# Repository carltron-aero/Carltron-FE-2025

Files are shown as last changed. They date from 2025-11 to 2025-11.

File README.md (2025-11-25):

# Team Carltron - Future Engineers 2025

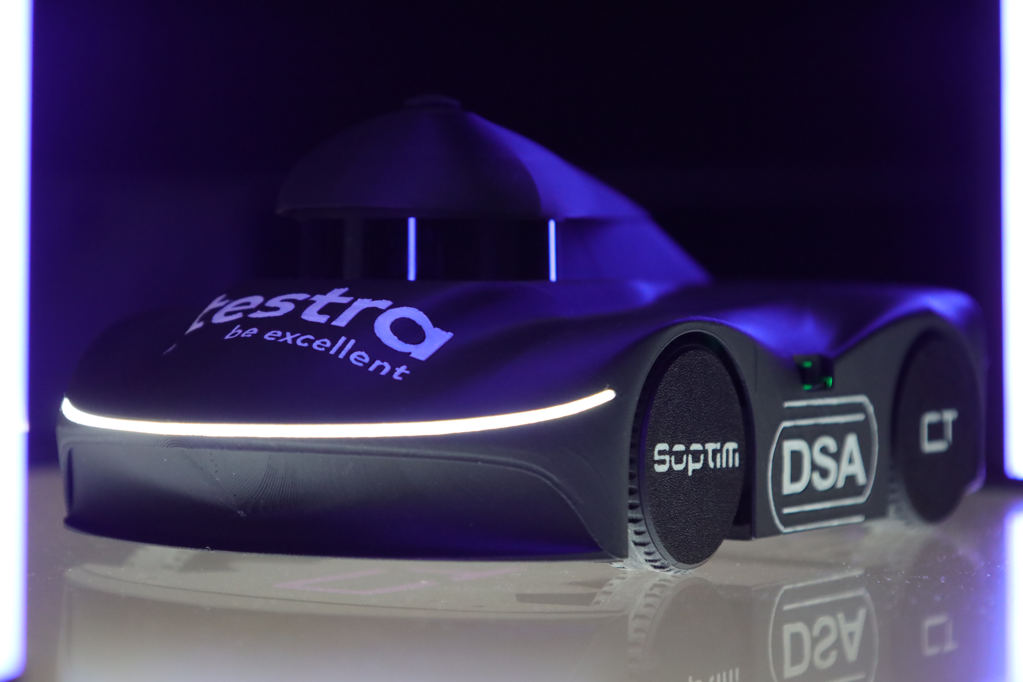
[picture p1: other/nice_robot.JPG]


<center>This is the Future Engineers project repository by team Carltron for the 2025 World Robot Olympiad International Final.
</center>

### Our Journey so far...
The 2025 season is actually our first season both in Future Engineers and WRO in general. After participating in multiple robotics competitions over the past few years, we were looking for a new challenge, when we found out about the Future Engineers Category in december 2024. Due to exams and other obligations though, we were only able to start working on our robot in April 2025, one month before our regional competition in Aachen, Germany. This challenged us to make our design strategies more efficient and also streamline our project management. After getting a working robot ready just in time, our first big moment came on the 17th of May at our regionals, where we managed to secure the qualification for the german finals by taking 1st place.
Our robot had jumped over the first hurdle, which was a big relieve and motivated us to go all in on the national 
competition. But not everything was well and good. Our first robot (V1) had also shown some flaws during its live 
competition runs, so we already had a long list of ideas on how to improve it and diminish or remove these issues. 
Development went on to the German finals, where we were able to secure 2nd place, qualifying us for the 
international final. Now, since than a lot has happened. A completely from the ground up new robot happened among 
others. But let's not spoil too much, cause that's what the rest of this documentation is all about, right?

## Design Strategy
As a basis for all decisions we would make in our entire process, both hardware, software and everything in between 
we first decided to lay down some fundamental design principles to help us make good decisions in the developement 
of our robot from the get go.

- For the general design of both our hardware and software systems, we always try to simplify all solutions to their 
base requirements. For example this means solving issues on the lowest level possible; hardware > software. 
- Question all common solutions: Why is something "always" done this way? Is it really the right approach for our 
  specific case?
- Minimize complexity! A highly complex system is hard to work with and will probably bring serious reliability issues.

# Mobility Management
## Motorization and Chassis

In the beginning of our preparations we looked at different kinds of robot kits and systems that we might build upon.
However, none of them seemed really perfect for what we had in mind. Either the form-factor wasn't quite right, the 
chassis would have needed significant changes anyway, or it just took away too many development opportunities.

So we decided to completely design our own vehicle from scratch using CAD software. That way we would also have 100 
% control over every ever so slight detail that would need to be tweaked.

We had already developed our core concentric sensor system previously, which already gave us a couple of constraints 
concerning the layout and size of the robot. And developing a concept for the layout of the robot with all of its 
biggest components was also the first main step we took towards developing the chassis of our robot.

Our 3D printer probably was the most important tool throughout our entire hardware-development phase. We printed all 
parts of our chassis in PLA Filament with fine-tuned printing parameters, which can be found in the printing files 
inside the */models* directory. By using 3D CAD designed Parts that we printed ourselves, we also managed to iterate 
through different design approaches quickly, in most cases with under one hour per hardware iteration.
 
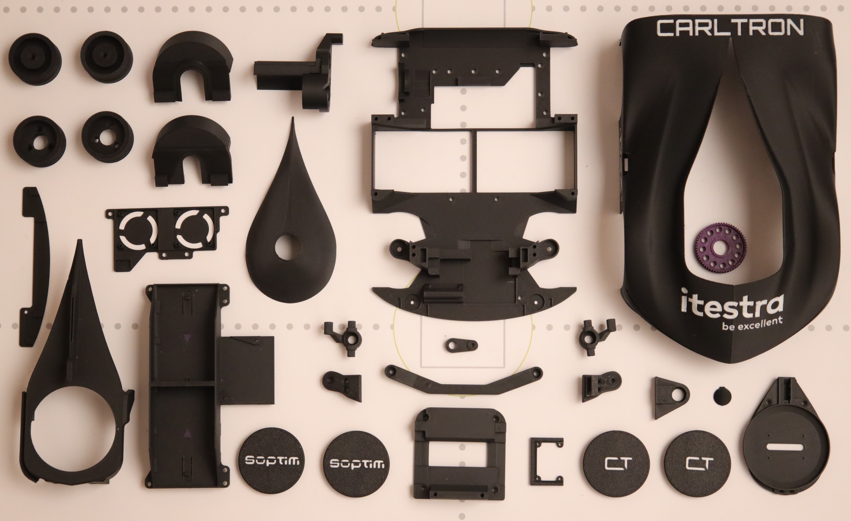
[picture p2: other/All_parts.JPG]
> 
> All 3d-printed Parts for the robot

### Drivetrain
For the choice of our drive system, the central factors were power and compactness. At first we considered
implementing an all-wheel drive with two steering axles for maximum maneuverability. But our research showed that
our robot would have to be significantly larger than planned for that solution to work.

From the outset we set a guiding principle for the robot’s development: every aspect of the design must aim for the simplest solution with the lowest susceptibility to failure. Accordingly, we performed calculations and experiments on turning circles and performance for different drive options to determine what the simplest overall system would look like that still fully meets our requirements:

1. It must reliably achieve a usable speed range of 0.12 to 1.4 m/s.

2. It must have sufficient traction to transfer motor power to the ground.

3. It must have a maximum turning radius of 0.55 m.

4. The steering must be able to transition fully from one extreme deflection to the other within 0.3 s.

In the comparison we found that a conventional approach—with the rear axle as the drive axle and the front axle used purely for steering—offered the best compromise between compactness and performance.
This configuration also gave us the opportunity to develop a fully custom steering system.

As in most cases, a lot of our chassis- and robot-development is rooted in well based design decisions.

#### Motor selection
For our main drive motor, we were primarily constrained by space it could get in the robot. When developing a 
conceptual layout, we found that we would need a 25 mm diameter motor would be just the right fit for our chassi.

As another strict requirement for the drive motor, we needed it to have an encoder, since we intended accurately 
control the physical wheel speed using the data from this sensor as well as distance data

So then we started looking for such a Motor, and actually fairly quickly found the Motor+Encoder combination we use 
till this day. It is a DC electric motor, that runs at 1000 rpm nominally.

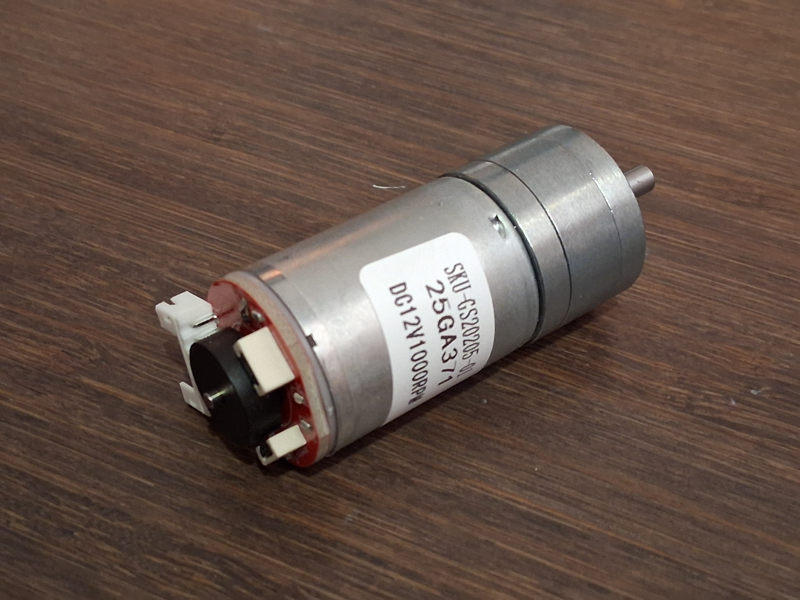
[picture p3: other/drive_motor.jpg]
>
> The drive motor theat was selected 

This motor theoretically also lets us fully use the required speed range from our development phase up to 1.5 m/s, 
however we found in testing the software that a limit to 0.75 m/s made a lot more sense in order for reaction times 
to still be adequate for avoiding crashes.
To ensure high agility despite using front-wheel steering only, a differential on the rear axle is very helpful
because it allows the driving wheels to move independently. This lets the inner wheel follow a smaller turning radius without unnecessary slip and without the wheels losing traction. At the regional competition we used an off-the-shelf rear axle with a differential. However, its precision and reliability did not meet our requirements. In addition, using this and other standard components in the drivetrain forced us to design the rest of the robot around those parts rather than integrating them well, since they were not developed specifically for our use case.

To keep the robot’s form factor small and maintain full flexibility in the overall design, we decided to develop
our own differential gearbox that would fit perfectly into the rest of the robot’s layout. We tested various 
bearings, gears, and motor couplings for this. Ultimately we developed the differential gearbox shown below, which—like 
most of the robot’s other components—was designed from the ground up by us in the 3D CAD software Onshape. We 
3D-printed the Differential in PETG-CF for its improved toughness and abrasion resistance. So far we have done about 
50h of testing without the 3D-printed differential showing any wear whatsoever. 
However, we bought the axle off the shelf for durability reasons.

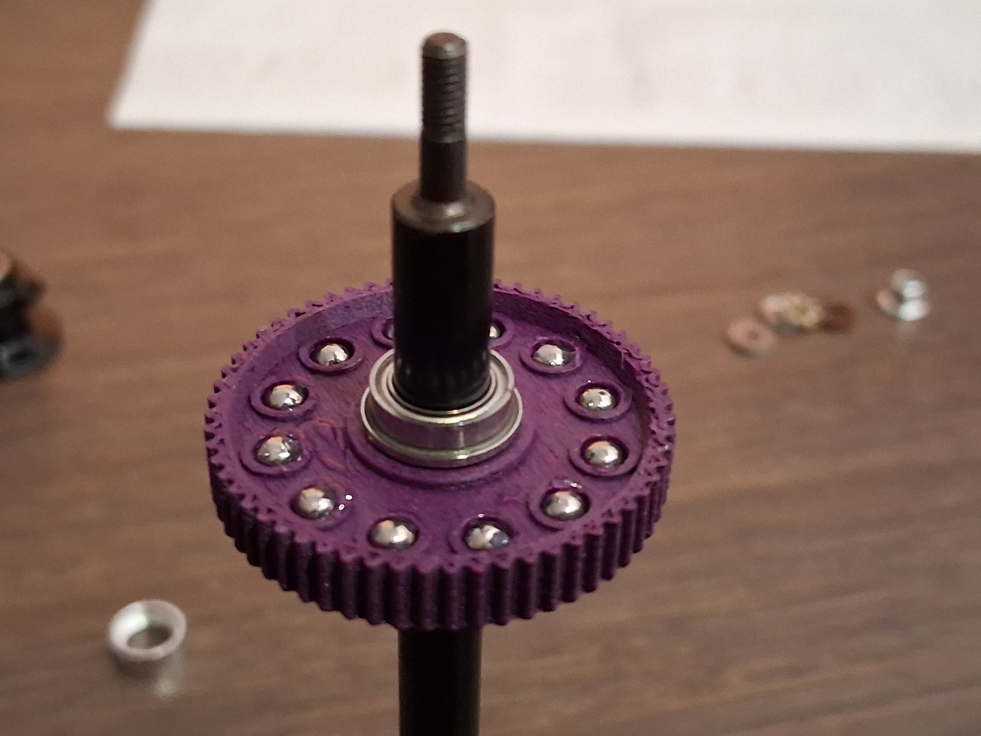
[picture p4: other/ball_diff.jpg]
> 
> Ball differential (half), purple part was developed and manufactured by us

The type of differential we ended up implementing is a so called ball-differential. While it achieves the exact same 
effect as normal geared differentials for the drivetrain, it takes a very different approach by using a double 
clutch design, that uses the spherical character of the balls to reverse the counter-rotation. 
A more detailed explanation of the ball diff can be found here: https://en.wikipedia.org/wiki/Ball_differential

Besides compactness, improved precision and efficiency, ball differentials also have a very distinct feature by 
default: They are so called "limited slip differential", meaning that we can fine tune just how much slippage we 
want to allow between the wheels to optimize for the best power transfer on the game field.

By developing this ball diff ourselves we also were able to perfectly tune the gear ratio to the drive motor, which 
is now 16:60. However, we could simply change this parameter if we wanted to adjust the velocity range of the robot.
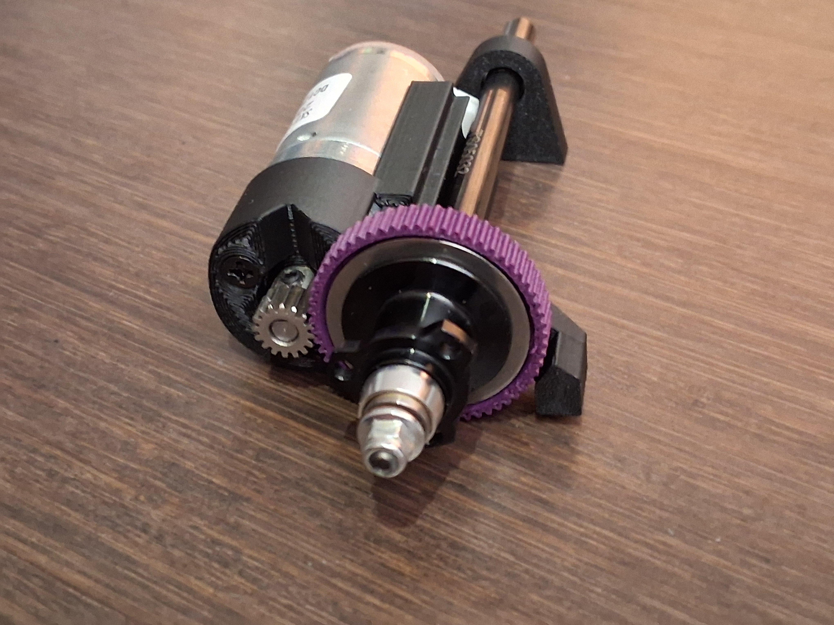
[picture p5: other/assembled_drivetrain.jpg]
> 
> Fully assembled drivetrain system

### Steering System

As part of our Drivetrain/Chassis Development process we had found that especially if we were to attempt the parking 
challenge, we would need to significantly improve the steering agility of the robot, to an extent that could not be 
achieved by tuning or using off the shelf components.

So we did a full redesign of the entire steering system, making it more compact and drastically increasing the 
steering angles. We finally managed to minimize the turning diameter of the robot to just 42 cm, falling well below 
the required maximum of 55 cm set in the development phase. This would come in clutch for leaving and entering the 
parking lot reliably, since now we could actually do it in one single motion, where previously multiple direction 
changes were required.

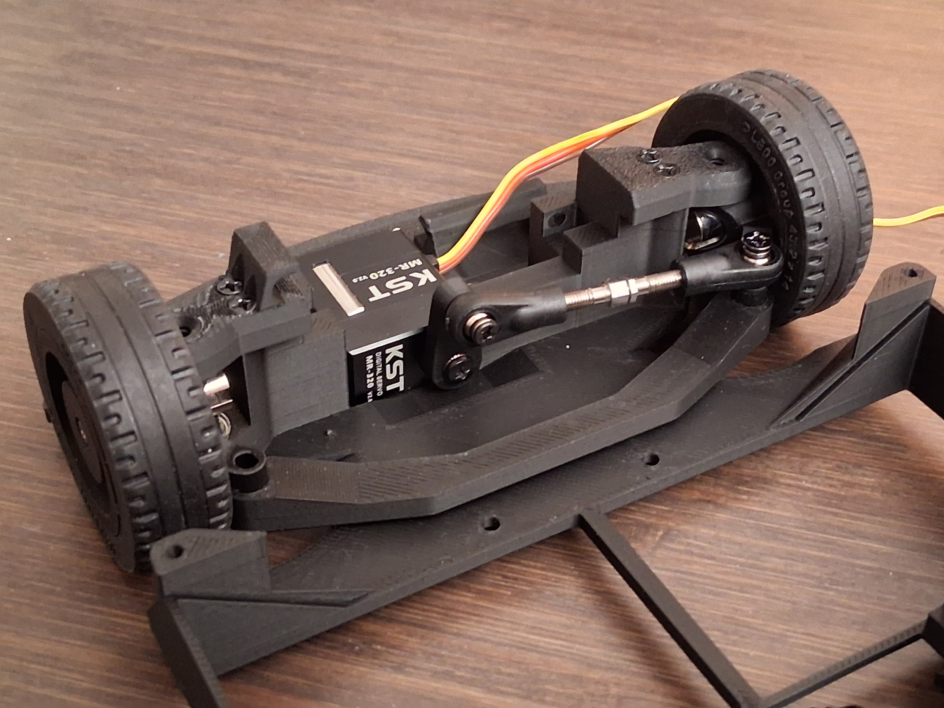
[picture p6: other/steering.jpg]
> 
> Newly developed Steering system for improved agility

We had previously used quite a large steering servo, that didn't work as reliably and didn't provide the speed and 
precision we set out to achieve with our new target values for the steering system.

So we went looking for a new Servo, fitting the requirement, comparing different models till we decided to use the 
KST MR320 180°. This smaller servo that actually provides better performance than our previous one also helped us 
significantly in optimizing the robot layout, since the our concentric core sensor assembly could now be lowered, 
giving it more margin for measuring imprecision.

In order to test our new steering kinematics we now also started using CAD based simulations, that allow us to go 
through all the required operational modes and movements, without requiring a lot of 3D-printing and subsequent 
plastic pollution.

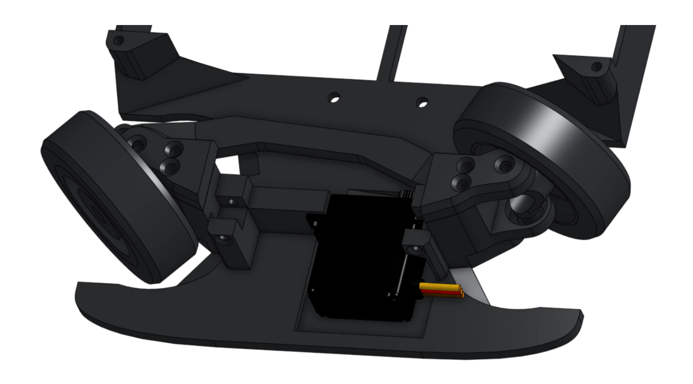
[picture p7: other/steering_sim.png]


### Bodywork

We developed a replaceable bodywork for our robot, that protects the components from environmental influences, 
directs the cooling airflow through the robot and provides it with front and rear lighting for status indications 
and more luminance for the obstacle scanning.

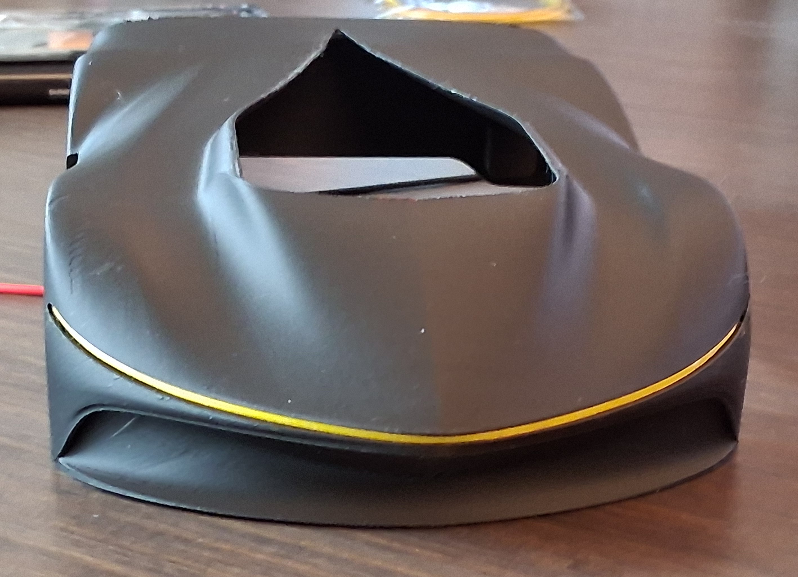
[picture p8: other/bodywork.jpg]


The bodywork gets held on the chassis magnetically, making it very easy to hot-swap whenever something needs done 
"under the hood".

### Aerodynamics

Another advantage of the bodywork we designed is the improved aerodynamic efficiency the bodywork provides to our robot.
We ran CFD (computational fluid dynamics) simulations as a virtual wind tunnel, to compare different versions in 
their aerodynamic characteristics.

This is a visualization of the latest simulation results:
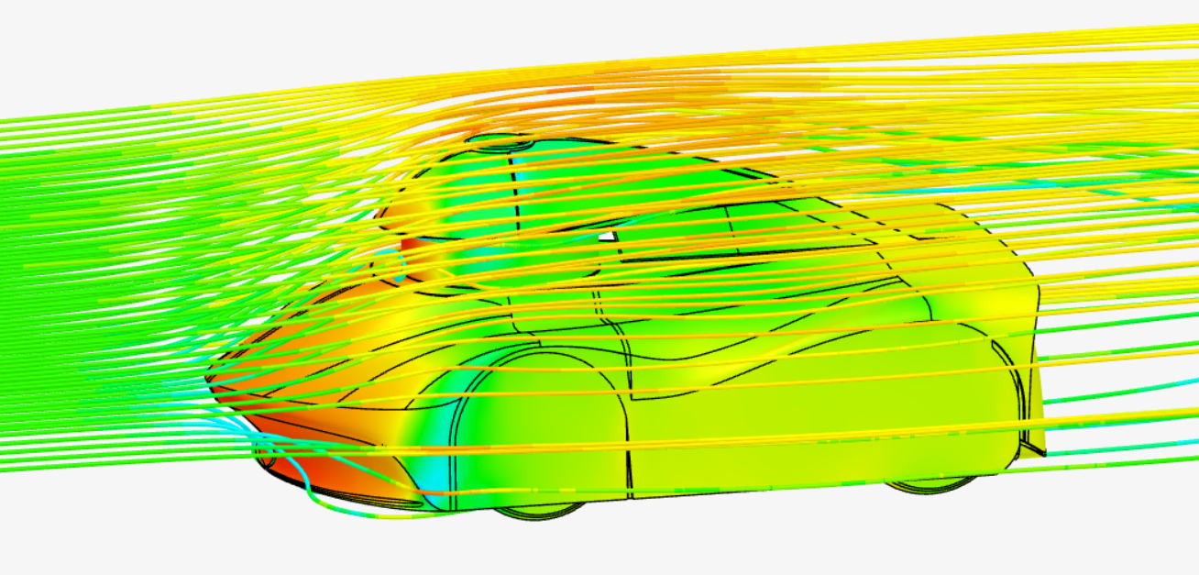
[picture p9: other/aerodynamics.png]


As you can see, we managed to create a clean air split along the front bonnet of the robot, guiding the air over two 
moulds in the bodywork towards the rear of the car without flow separation. By extending the rear spoiler overhang 
we managed to almost completely remove any vortices caused by rearward flow leaving the vehicle, which is especially 
important to reduce the overall drag of the vehicle.

The simulation however for example also shows that the round surface of the lidar scanner causes some vortices to 
form in th low pressure zone right behind the sensor, which would be one of the next step to be mitigated in terms 
of aerodynamic optimization.

And just as a disclaimer: You are right to assume that these kinds of aerodynamic optimizations do not really have 
any measurable effect on the scale and speeds that Future Engineers is running on. But for us this is all about 
trying new and interesting things. We were able to learn very much about aerodynamics by doing these simulations and it 
even was a lot of fun trying it out. Can recommend.

# Power and Sense Management

## Compute

Before any data from any kind of sensor becomes really useful, there has to be an algorithm that uses it to create 
some kind of outcome. And for that algorithm to become useful it needs to run on something - so it seems like we 
need a computer.

We have previously already worked with Raspberry Pis and in this case the versatile GPIO capabilities of the 
Raspberry Pi 5 combined with its small footprint and its well maintained codebase as well as a great community made the 
choice easy. We chose to use the Raspberry Pi 5 8gb, to be sure that enough memory would be available for our high 
speed camera frame buffer.

## Sensors

The selection of sensors is obviously one of the most defining characteristics in the concept of any Future 
Engineers robot. So let's start with a first principles approach to figure out, what kind of sensors are required to 
achieve the strategy we intended to implement.

Since our goal was to design a robot that could reliably localise itself on the playing field in 
any place or situation, we found that we would need sensors that could give us a reading of the robots 
physical surroundings in real time, which could be used for multiple purposes such as obstacle detection, 
localisation and collision avoidance. By taking a closer look at the actual playing field were working with in the 
Future Engineers category, we can see that all walls, barriers and obstacles are on a single flat level, or in other 
words a single plane. This is because all of these relevant objects on the playing field have the same height of 100 mm.

If we can get a planar 360° reading of our physical surroundings we can from any point of the playing field see so- 
called "characteristic spots". Examples of such spots would be the corners of the outer and inner walls, the 
barriers of the parking lot or the placement of specific obstacles. As long as our planar reading is precise enough 
and has an adequate resolution, we, theoretically, can do all localisation, navigation and path planning based on 
this single 360° sensor reading.

Well, the great thing is, because we are not the first humans tackling challenges of autonomous navigation, there 
already are quite mature sensor technologies that can give us the exact 360° physical reading that we need: They're 
called 360° Lidar sensors. 

Lidar (Light Detection and Ranging) is a Laser-based distance measuring technology that works by sending out light 
beams and measuring the time their reflections from any objects take to return. Since lightspeed is constant, this 
technology can give pretty accurate distance readings, whilst having a much more targeted measuring window (e.g. 
compared to ultrasound distance sensors). 

But what makes these sensors give 360° readings of their surroundings if they have such a targeted range? It's 
kind of simple but also genius: You simply spin the sensor really fast (multiple times per second). By doing that 
whilst taking multiple thousand readings every revolution of the sensor, you get a full 360° view with distance 
measurements in all directions.

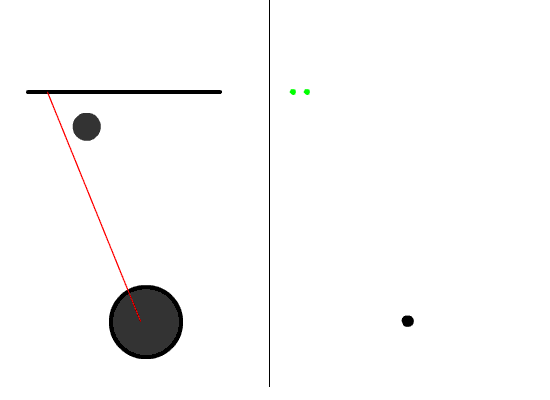
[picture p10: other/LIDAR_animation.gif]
>
> 
> Animation of the concept of a 360° Lidar Sensor

After finding the right type of sensor for our application, the next step is selecting a specific model that 
perfectly suits the requirements set by our specific challenge.

Since our robot will have to use the sensor readings while driving, we need the sensor to provide us with readings 
regularly. Our testing showed that a rate of 10 hz worked to an acceptable extent while best results could be 
achieved using sensors running at 15 hz or more. 

Concerning the resolution of the sensor, we need it to detect the obstacles that only have a 5 cm width from the 
robots' perspective, at a range of up to 2 m.

We also need a sensor performance, that can reliably detect the black walls of the game field both at ranges of up 
to 4 m and shallow angles, which could arise when driving close to a wall.

Also, importantly, we need it to have a form-factor, that lets us easily integrate it into our robot and that fits 
under the 10 cm height, so we can actually get the sensor reading in the plane of the game field.

We created this decision matrix to help us find the ideal 360° Lidar sensor:

| Criterion | **RPLIDAR S3** | **RPLIDAR S2** | **D900 / LD19 Plus** | **RPLIDAR A2** |
|---|---|---|---|---|
| **Update rate ≥10 Hz** | 🟢 10–20 Hz adjustable | 🟢 10 Hz fixed | 🟡 6–13 Hz range | 🟢 Up to 10 Hz |
| **Best at ≥15 Hz** | 🟢 Supports ≥15 Hz | 🟡 Limited to ~10 Hz | 🟡 Upper end ~13 Hz | 🟡 10 Hz max typical |
| **5 cm @ 2 m resol.** | 🟢 0.1125° ultra fine | 🟢 0.1125° ultra fine | 🟢 ~0.7–0.8° sufficient | 🟢 Fine enough for 5 cm |
| **Range margin beyond 4 m** | 🟢 40 m max range | 🟢 30–50 m variants | 🟢 12 m radius | 🟢 12–16 m range |
| **Black wall @ 4 m** | 🟢 10% refl. to 15 m | 🟢 10% refl. to 10–15 m | 🟡 Spec at 70% refl. | 🟡 Dark targets less specified |
| **Shallow-angle dark surfaces** | 🟢 Optimized low-reflectivity dtof | 🟢 Good low-reflectivity handling | 🟡 DTOF, less data published | 🟡 Triangulation, more sensitive |
| **Height < 10 cm** | 🟢 ~41 mm total height | 🟢 ~38.9 mm height | 🟢 ~33.5 mm height | 🟢 ~41 mm height |
| **Compact footprint for small robot** | 🟢 55×56 mm compact body | 🟡 77×77 mm footprint | 🟢 ~38×38 mm footprint | 🟡 Larger A-series footprint |
| **Eye safety, outdoor light** | 🟢 Class 1, 80 kLux resistant | 🟢 Class 1, IP65 rated | 🟢 Class 1, 30–60 kLux resistant  | 🟡 Indoor-oriented, less robust  |
| **Integration ecosystem, ROS support** | 🟢 Strong ecosystem, drivers | 🟢 Same Slamtec ecosystem | 🟡 Good, but more fragmented | 🟢 Widely used, many examples |
| **Cost level** | 🟡 Higher, premium Slamtec | 🟡 Mid-high price tier | 🟢 Low-mid price range | 🟢 Affordable A-series choice |
| **Form factor for 10 cm plane** | 🟢 Ideal low profile scanner | 🟢 Low optical window height | 🟢 Very low, cube-like | 🟢 Fits under 10 cm |
| **Overall match to requirements** | 🟢 Best fit for challenge | 🟡 Very strong alternative | 🟡 Good budget compromise | 🟡 Usable, but less optimized |

So the choice fell to the RPlidar S3 Sensor. Especially its ability to provide us with adequate resolution at a 15 
hz rotation rate due to its high sample rate, made the best choice clear to be this one. 

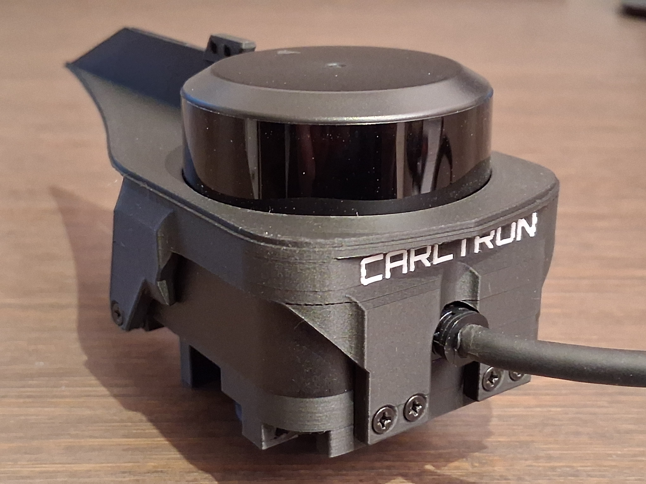
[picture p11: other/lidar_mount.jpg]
> 
> RPlidar S3 Sensor installed on its mounting hardware

Since we want to be able to use the 360° Lidar capabilities of this sensor to its fullest abilities, we decided to 
design our robot, so that the Lidar sensor would have an unobstructed surround view. This simply means that now 
components of the robot should reach into the field of view of the Lidar. But the sensor also should still sit well 
underneath the 10 cm top height mark of the walls and obstacles. Sitting to high might cause the sensor to simply 
look "over" obstacles and walls, as soon as the lidar sensors mounting is not perfectly plane. the closer we can 
bring the Lidar sensors measurement plane to the height middle of the 10 cm game field height, the better.

Getting physical 360° planar readings already gets us quite far in perceiving precisely what kind of obstacles are 
placed where and how to avoid them. But one crucial bit of information for the Future Engineers Challenge is still 
missing and can not be determined just by the readings from our Lidar sensor: The **color** of the obstacles. 

Since the detection of the color of the obstacles has to be performed on different angles from the point of view of 
the robot, a camera with a wide field of view is commonly used to tackle this and similar challenges. In most cases 
the camera simply looks forward in the driving direction and depending on the setup, the position of the obstacles 
is either determined by the camera image directly, only providing relative readings, or by use of primary physical 
sensors such as a 360° lidar sensor giving absolut position readings.

In both cases, with the camera simply mounted forward facing, either image analysis has to be 
performed on each whole frame to find the obstacles using visual cues, or a conversion from the physical planar 
readings of the lidar to the different perspective of the camera frames has to be done. Both of these common options 
can become quite compute intensive and cause lag as well as creating another possible source of unreliability.

So we tried to come up with a more efficient and reliable way to both detect the obstacles position and their color.
After trying out different set-ups and configurations, we found a novel technique that required some special 
modifications, but allowed us to skip the compute intensive full frame analysis on each camera frame entirely and 
without any conversions.

### Camera

Our approach: We can reliably detect the obstacles and their position using the Lidar sensor, just not their color. 
From the Lidar data we directly know the exact angle in the circular Lidar scan, the obstacle is located at from the 
Lidars' perspective.
Now, what if instead of the camera having a different perspective than the Lidar sensor, it simply had the exact 
same perspective? How can we get the camera to provide us with a 360° planar view just like the Lidar sensor?

We use a **custom 360° camera**.

We found a camera lens that provides a circular field of view of 222° and modified an existing camera sensor module 
based on the IMX219 Sensor
to capture the full image circle of this lens. And yes, that fov is more than 180°, meaning that the 
camera can basically look behind its own sensor plane. Since we capture the full image circle (meaning all light
the circular lens shines out its back), this actually goes for all directions from the center of the frame in the 
exact same way.

For visualisation, this is a sample frame taken from the custom 360 camera:

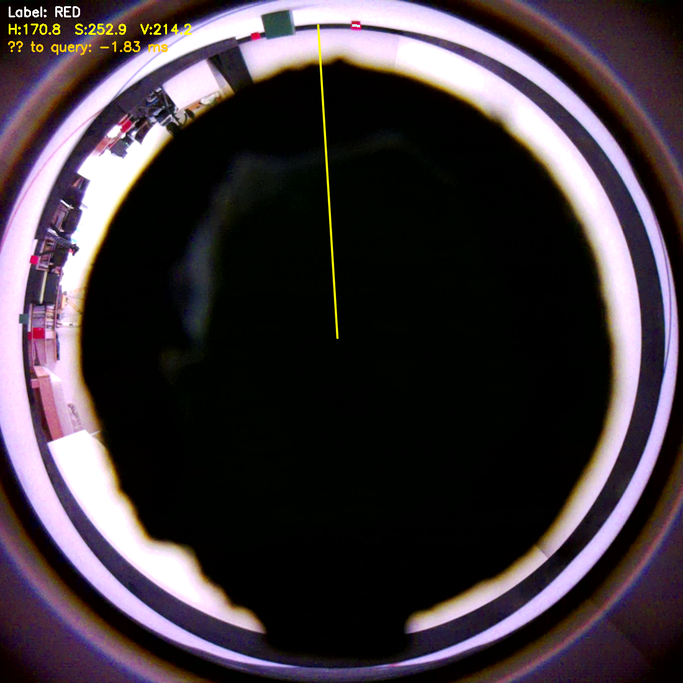
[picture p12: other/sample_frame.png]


As you can see, the camera is positioned on the game field looking straight upwards. You can also see, that the 
camera has a clear view of all walls of the game field all around itself. This means that, as is also visible by the 
various colored obstacles positioned on the field for the sample frame, the camera has a 360° view of all the 
obstacles. 

But there is still one difference to the lidar data: While the lidar directly gives us planar readings of the 
sensors surroundings, the camera captures part of an optical sphere that converges to a single point. In order to 
analyze a plane with the surroundings of the camera, we simply have to look at a ring-shaped region of interest in the 
frame 
that has a fixed radius. This radius has to be chosen precisely so that it is on the same exact plane as the camera 
sensor.

And with all that in place, we simply position the camera sensor directly over the center of rotation of our lidar 
sensor but still under the 10 cm max height of the obstacles, et voilà - we have a camera that gives us a planar 
360° reading that is concentric with the planar 360° reading of the Lidar.

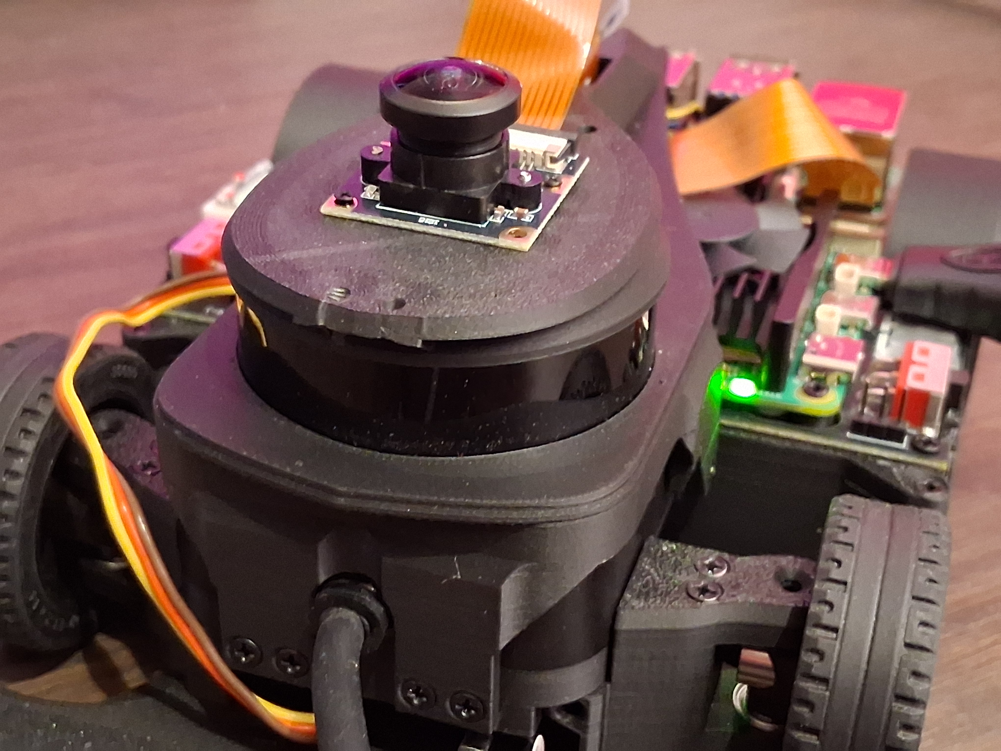
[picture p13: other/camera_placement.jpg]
> 
> 360° camera positioned concentric above the lidar sensor

This means that we can simply 1:1 map the angles from our Lidar scans, on which we detect obstacles, onto our camera 
frames. Instead of analysing the frame for obstacles, we just have to detect them physically using Lidar and then 
just get the color reading on a couple of pixels on the corresponding angle of our ring-shaped region of interest in 
order to tell the color of any detected obstacles. 

Since no actual image analysis has to take place, and we also don't need any conversions for the different sensor 
perspectives, our color detection actually only adds on the order of a few milliseconds to any obstacle analysis, 
making it much more efficient than any other approaches we tested.

This special approach to the lidar - camera  combination for obstacle and color detection is also a great example of 
our fundamental design strategies: Instead of simply using the standard approach of mounting the camera forward 
facing - following the motto "we'll fix that later in the code...", we reduced the issue to its core and came up 
with novel approaches until we found one that is both simpler more reliable and efficient for this specific challenge. 

Mounting the camera on top of the Lidar sensor however also comes with a noticeable downside: The data from the 
camera has to somehow come from above the lidar scanning plane below it - to where the rest of our electronics 
resides to analyse the data. So somehow, the camera cable has to cross through the field of view of the Lidar sensor.
To mitigate the effect of this, we decided to put our so called "shark fin" behind the lidar sensor, that allows a 
flatband cable for the camera to reach the Raspberry Pi whilst also holding the custom camera housing and mounting 
structure.

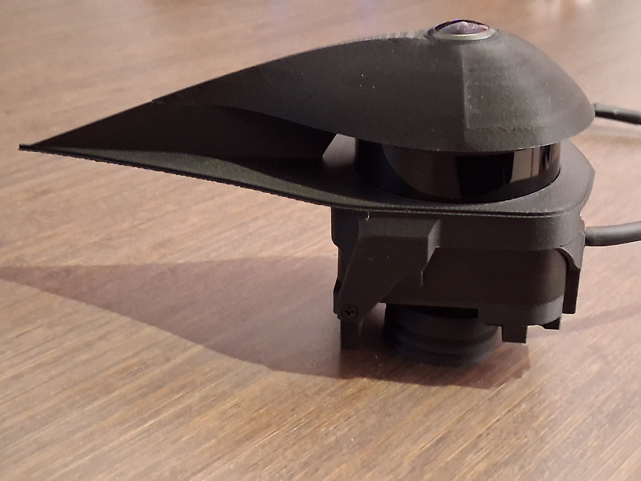
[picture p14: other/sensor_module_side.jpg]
> 
> Assembled sensor module with Lidar sensor, shark fin and camera on top with the camera housing

As might have already caught your attention looking at the sample frame provided earlier, the center of the frame 
inside of the ring-shaped region of interest is actually blacked out in the sample frame. This is due to us 
employing a small partial lens cap, that simply blocks any lights from shining on the camera sensor from directly 
above in order to improve  color precision during the challenge.

### Other Sensors

While Lidar and camera theoretically could provide enough information to fully solve the Future Engineers challenge, 
in practice some secondary sensors are also needed to improve performance and get precise readings for specific 
aspects on the robot.

The first additional sensor is our IMU (inertial measurements unit), which combines a gyroscope with a magnetrometer 
and additional acceleration readings. For its reliability and internal sensor fusion capabilities we chose the 
BNO085 IMU. We mainly 
use the 
gyroscope, both as part of our drive control 
algorithms to 
keep driving in a straight line as well as a secondary check for the localisation algorithm to make sure we're 
always using the correct regions of interest on a specific side. It also is used to count the solved sections in the 
open challenge

We also specifically chose a drive motor with an encoder. An encoder allows us to precisely measure how many 
revolutions our motor (and therefor the wheels) does in any given time frame, which lets us read both the physical 
distance our wheels have done as well as the actual physical speed were currently doing, decoupling driving a 
specific distance or at a specific speed from guessed timing values and changing battery state of charge (etc).

## Power Supply

### Selection of batteries

In order to determine the kind of batteries we would need to adequately power our robot, our first step was getting an overview of the power consimption of all the components we intended to use:

| Component | Power in W (peak, including voltage conversion losses) |
|---|---|
| Drive Motor | 14 |
| Steering Motor | 11 | 
| Raspery Pi | 15 |
| Lidar Sensor | 4 |
| Various Sensors / IO (IMU, LED, Camera, etc.) | 4 |
| **Sum** | **48** | 

>*These wattage values were obtained by combining values from the specific data sheets of the components as well as our own measurements.*

So, our batteries would need to provide ~50 Watts at peak. Our own measurements show, that over long term running, our specific system requires an average of 22 Watts constantly.

Additionally, we want to run our drive motor directly off the batteries without a voltage conversion. This is because any conversion losses would directly impede the performance of our drive train. Minimizing the required components (another converter in this case) also follows our general design strategy to keep all system aspects as simple as possible. To run our drive motor off the batteries directly, they need to provide provide a voltage between 14 - 18V.

As additional requirements, we want our batteries to be widely available in case we need to get spares, not too expensive, safe while in use and charging and we want to use a quick connect/disconnect system, that lets us swap out batteries with ease. They should also give us enough capacity to do at least an hour of testing on one battery to save time, so the batteries need to provide a capacity of at least ~30 Wh.

So we compared different kinds of commonly used batteries for our requirements:

| Criterion | 2× **LP-E6** series | 4S **LiPo RC** pack | 4S **18650 Li-ion** pack | 12-cell **NiMH** RC pack |
|---|---|---|---|---|
| **Voltage** | 🟢 16 V nominal | 🟢 14.8 V nominal | 🟢 14.8 V nominal | 🟢 14.4 V nominal |
| **Energy** | 🟢 ~39 Wh pack | 🟢 ~33 Wh pack | 🟢 ~38 Wh pack | 🟢 ~43 Wh pack |
| **Density** | 🟢 High Li-ion density | 🟢 High LiPo density | 🟢 Very high density | 🟡 Lower specific energy |
| **Peak power** | 🟢 3.5 A, ~56 W | 🟢 Very high current | 🟢 Several amps continuous | 🟢 High discharge capability |
| **Availability** | 🟢 Widely sold camera battery | 🟡 Hobby / RC channels only | 🟡 Cells common, packs niche | 🟡 Declining RC availability |
| **Safety** | 🟢 Protected, low risk | 🔴 Damage, fire risk higher | 🟡 Needs BMS protection | 🟢 Chemically very robust |
| **Charging** | 🟢 Simple LP-E6 chargers | 🟡 Requires balance charger | 🔴 BMS-aware charger needed | 🟡 Dedicated NiMH charger |
| **Swap mech.** | 🟢 Latching sled, foolproof | 🟢 XT plug quick swap | 🟡 Less standardized packs | 🟡 Bulky stick swapping |
| **Durability** | 🟢 Hard plastic shell | 🟡 Soft pouch, fragile | 🟡 Depends on pack case | 🟢 Rugged cylindrical cells |
| **Cost** | 🟡 Higher cost per Wh | 🟢 Lowest cost per Wh | 🟡 Moderate cost per Wh | 🟡 Moderate, heavier packs |
| **Form factor**  | 🟢 Compact brick | 🟡 Flat pouch, padding | 🟡 Cylinder cluster, bulky | 🟡 Long stick, heavy |
| **Overall match**| 🟢 Best system-level fit | 🟡 Acceptable, worse usabiliy | 🟡 Acceptable, complex integration | 🟡 Not adequate, heavy and bad usablity |

Due to their safety track record, wide availability, flexibly integrable form factor and standardized mounting system, we decided to use two LP-E6 type batteries running in Series. These provide up to 6 A at approximately 8 V each. Therefore, when connected in series, these two batteries giving us a total power capacity of around 56 W at 16V, nicely fitting our power requirements with some margin. 

### Voltage Management

Our different components each require specifc voltages which we need to supply to them reliably:

| Voltage | Components |
|---|---|
| 3.3 V | IMU, Camera, Motor Encoder, IO-LEDs, Lighting Bridge |
| 5.1 V | Raspberry Pi, Lidar Sensor |
| 8.4 V | Steering Servo, Cooling Fans |
| 16.0 V  | Drive Motor |

So there are four discreet voltage rails that need to be supplied reliably:

Our Raspberry Pi already provides an internal 3.3 V rail, that is used both for logic IO and power supply up to 500 mA for external components via the GPIO, which is more than enough for the Sensors and IO we want to run at 3.3 V, since they require a combined maximum of ~380 mA.

Both the Lidar Sensor and the Raspberry Pi need to be supplied with 5.1 V. While the Raspberry Pi can be supplied with up to 5 A, this is only necessary when running power hungry external components on its USB Ports. Since we do not use the USB ports during operation, we can still run the Pi 5 at full power when supplying int with 3 A. Our Lidar Sensor requires a maximum of 0.8 A on startup, bringing our total required power on the 5 V rail to 3.8 A. We decided to use a 5 A Step-Down Buck Converter for the 5 V Supply that is connected as seen in our Power Rails diagram.

At 8.4 V, the cooling fans of our robot use ~250 mA each and our Steering Servo needs ~1.4 A at peak. They are supplied by a smaller 3 A Step-Down Buck Converter.

The drive Motor is run directly off the Batteries, removing the need for any additional converters. Changes in the supply voltage based on the batteries state of charge are fully mitigated by our encoder-based drivetrain controller algorithms, as will be discussed later in the documentation.

This schematic provides an overview of how the different voltage rails are connected:
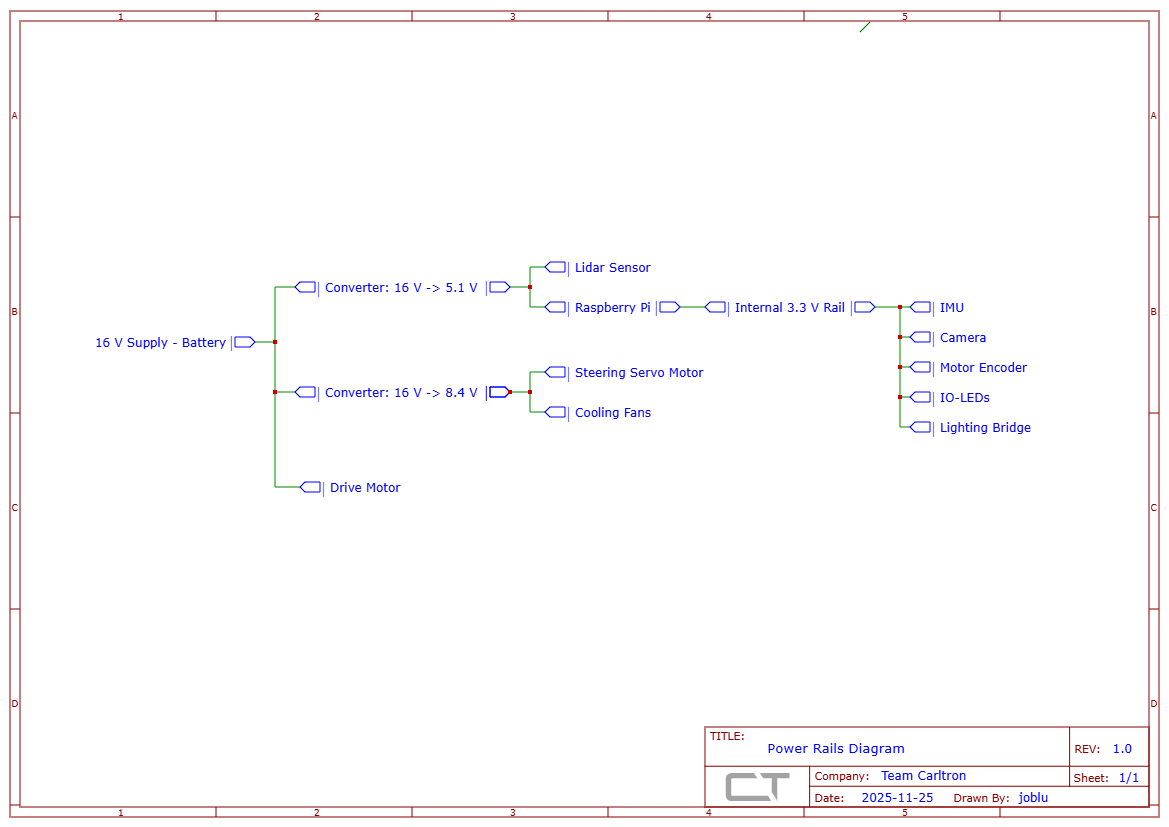
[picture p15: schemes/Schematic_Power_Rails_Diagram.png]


The separate Buck Converters used for the 8.4 V and 5.1 V rails also decouple all the sensitive electronics and sensors from our drive train power systems, preventing any voltage ripple and inconsistencies caused by sudden power changes in our drivetrain and steering systems.

To operate the Raspberry Pi and the batteries under optimal conditions, we also installed an actively air-cooled heatsink on the Raspberry Pi, as well as passive cooling elements on the voltage converters. In addition, we mounted the two main cooling fans under the rear of the robot to provide constant airflow from the front wheel housings, across all electronic components and converters, and out through the bottom of the chassis. These fans fully replace the air inside the robots bodywork every 4 seconds, making sure that all components can run at peak performance without getting hot.

### Custom Mainboard

For distributing power to the various components and ensuring communication between the electronic modules and sensors, we designed our own custom mainboard and had it professionally manufactured. 

This was especially interesting to us, since we learned a lot about electrical engineering by doing all the conceptualisation, design, layout and manufacturing information on our own.

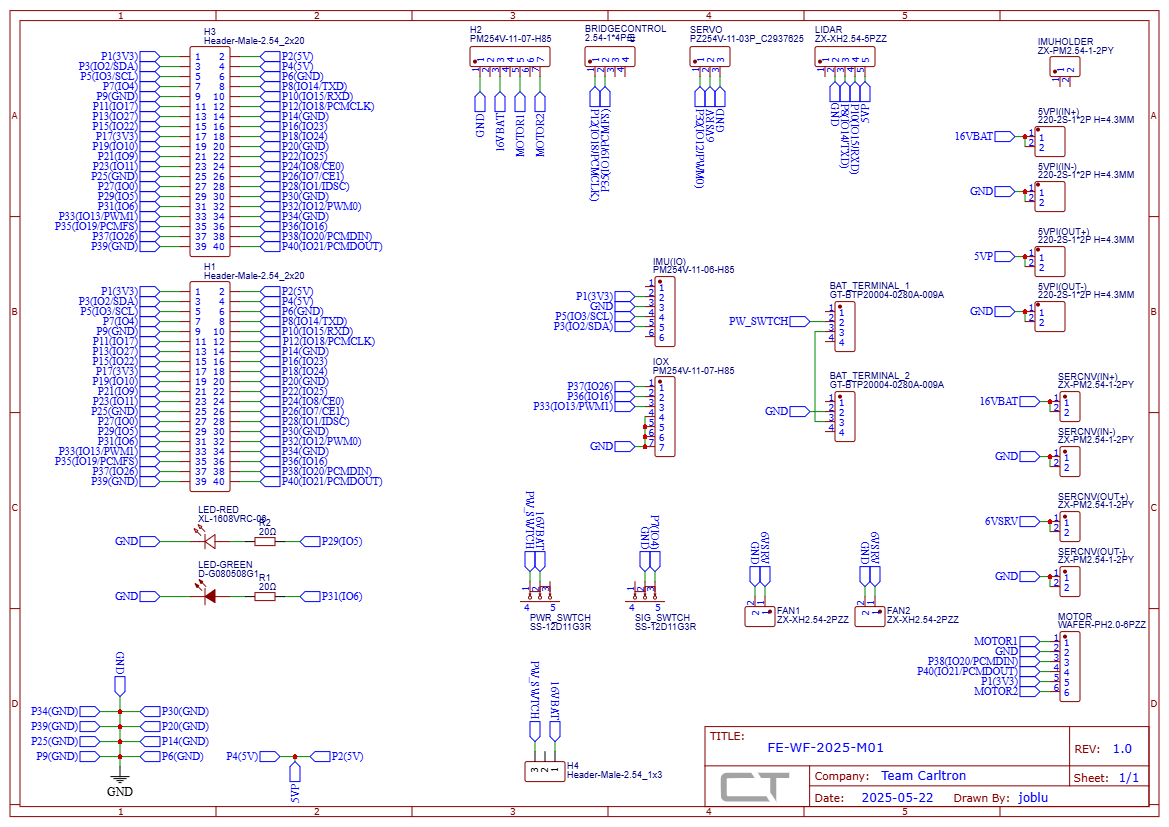
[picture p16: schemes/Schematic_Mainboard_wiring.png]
>
>Wiring schematic of our custom Mainboard

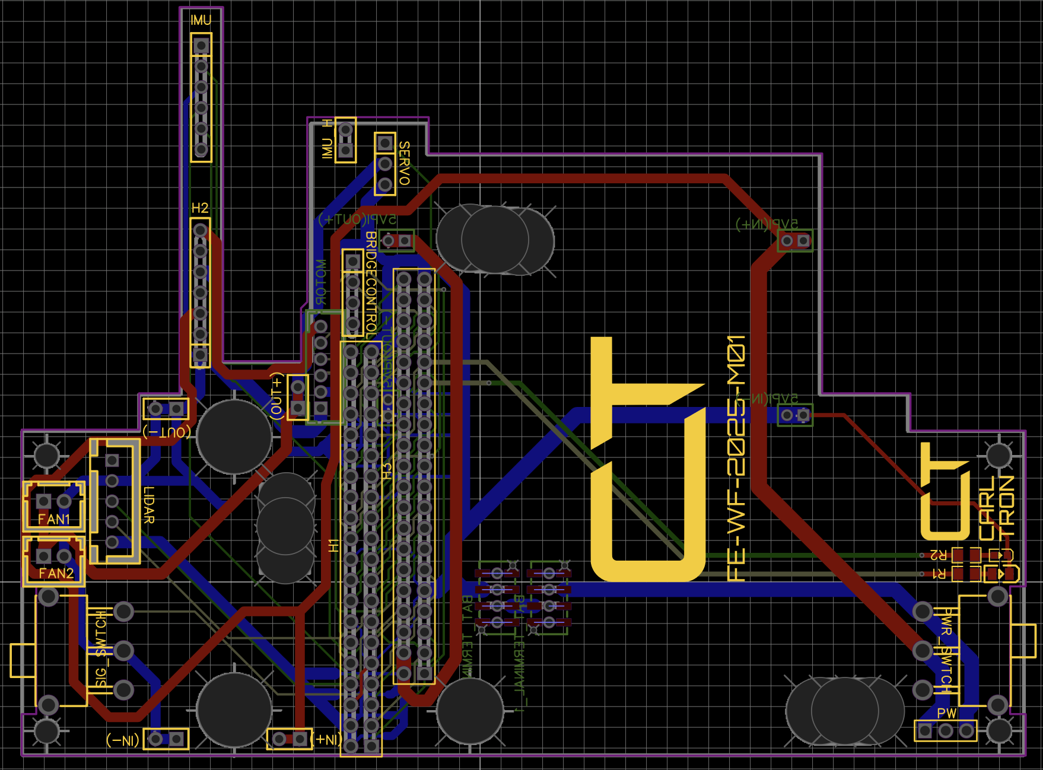
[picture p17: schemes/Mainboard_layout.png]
> 
> Actual layout and routing of the PCB (Printed Circuit Board)

This custom Mainboard PCB provides a significantly more efficient and reliable solution compared to the numerous 
cables we previously used to connect the components.

| PCB Top Side, no components | PCB Bottom Side, no components |
|---|---|
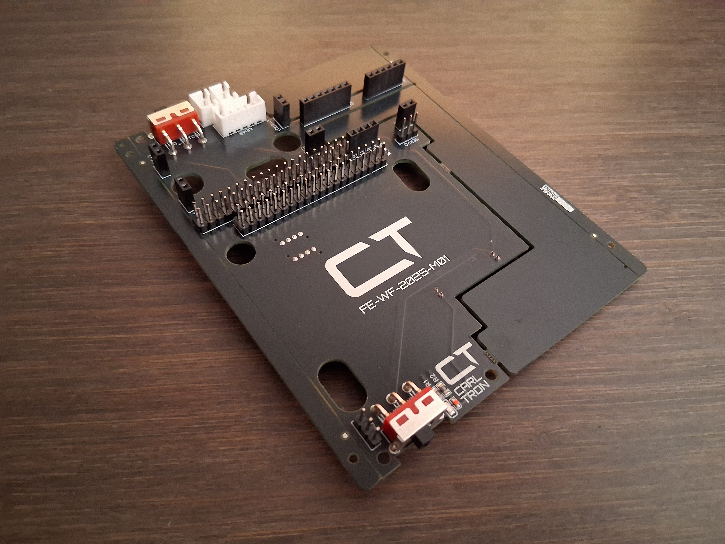
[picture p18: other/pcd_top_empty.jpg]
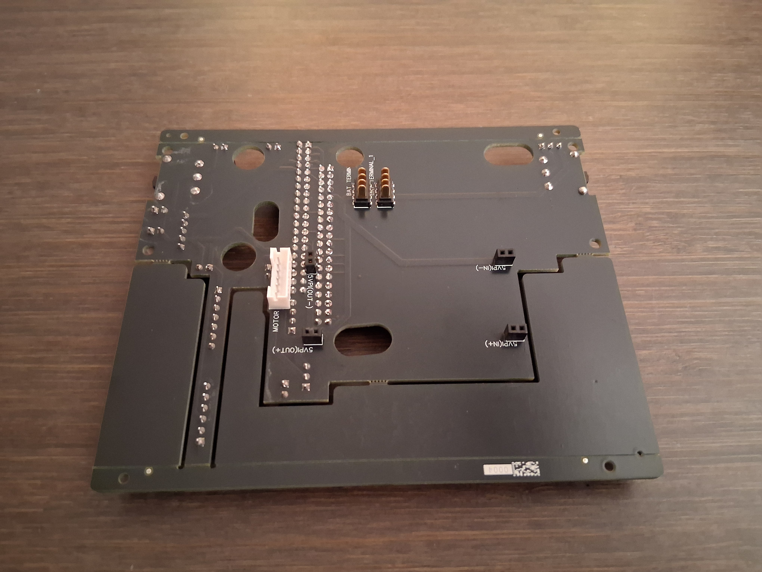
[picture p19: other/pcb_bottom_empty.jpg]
|  |  |

Since a lot of data connections had to be routed through this Mainboard without interfering with each other, we decided to make it 4-layered with components placed on both sides of the board for maximum compactness.

Both the two voltage converters, the drive motor bridge, the IMU and the Raspberry Pi are mounted directly onto the Mainboard, while cable conectors on the Mainboard facilitate the connections to the drive motor itself, the lidar sensor, the steering servo and the cooling fans.

The Mainboard also directly integrates seamlessly with our custom battery holder. On the bottom side of the Mainboard, small connection pins allow the batteries to directly connect to the Mainboard when inserted.

| PCB Top Side, assembled (with battery holdder) | PCB Bottom Side, assembled (with battery holdder) |
|---|---|
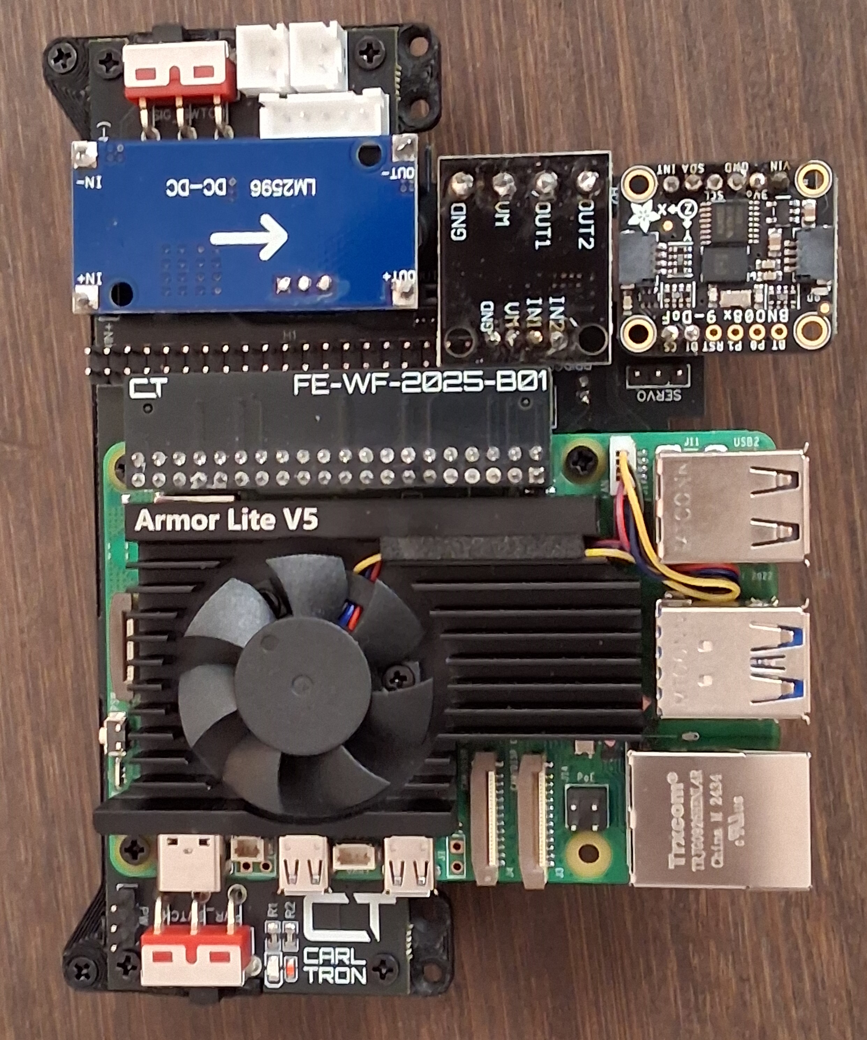
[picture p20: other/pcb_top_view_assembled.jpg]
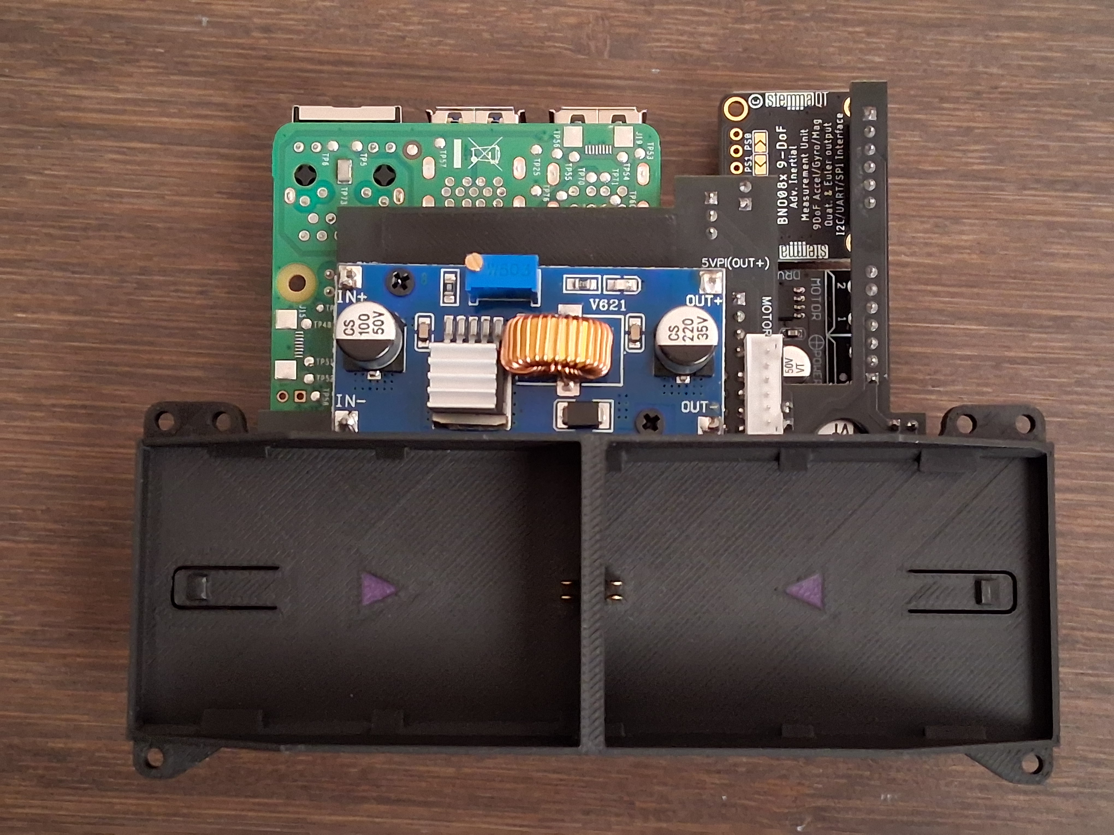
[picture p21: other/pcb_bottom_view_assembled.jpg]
|  |  |

In order to connect the Raspberry Pi with the Mainboard, we also designed a custom adapter PCB, that directly 
connects all GPIO pins of the Pi.

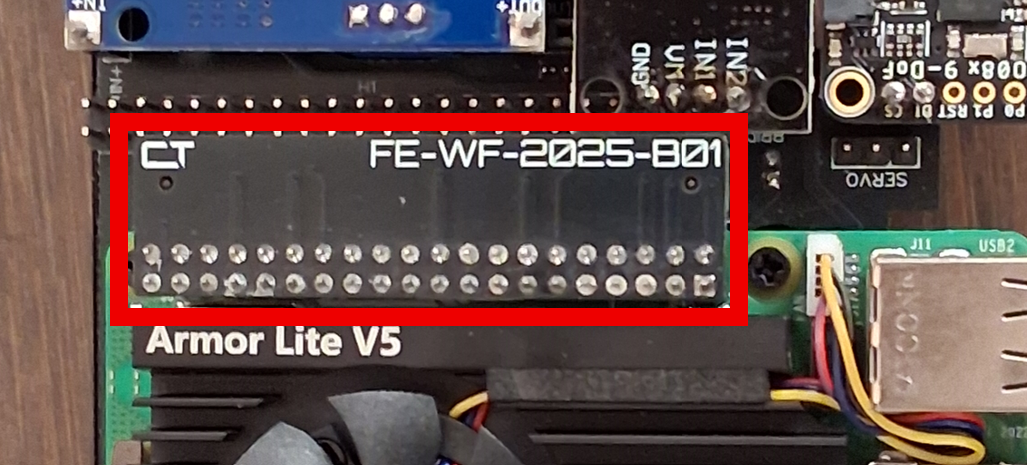
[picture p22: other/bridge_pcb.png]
> 
> Adapter bridge connecting the Pi's GPIO to our Mainboard

For all components that were directly mounted onto our custom Mainboard, we used soldering for the connectors.

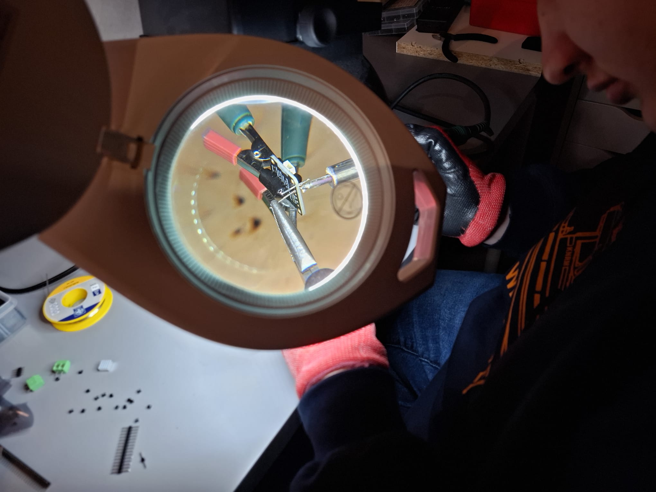
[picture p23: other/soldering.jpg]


### IO
In order to start our robot for the run and to always be able to tell its current state at a glance, we equipped or 
robot with a set of I/O features.

Since power management and GPIO distribution are both done by our Mainboard, we were able to simply place a
switch on each side of the Mainboard that control the power and the program start as required by the rules. There 
are specific cutouts made in the replaceable bodywork of the robot that allow easy access to the switches for use in 
the competition.

In order for the robot to display its current state while the code is running, we added a green and a red led to our 
main board, that are animated in specific ways to tell the different modes and states of the robot code apart at a 
glance. 

These Mainboard-leds are not visible though, when the replaceable bodywork is in use, since it covers up the 
internal components. To still display the state of the robot, we added a red rear light bar to the bodywork that 
mirrors 
the behaviour of the red Mainboard-LED.

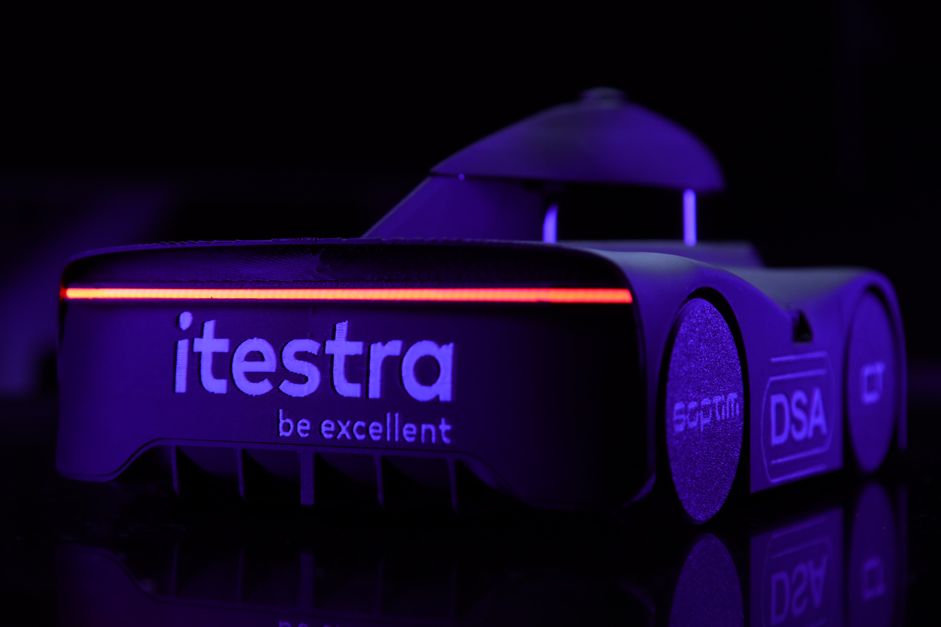
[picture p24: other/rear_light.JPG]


We also added a white light bar to the front of the bodywork that also provides a much higher light output and 
mirrors the green Mainboard-LED. The front LED-Bar is used to light up the obstacles when scanning them in each zone.

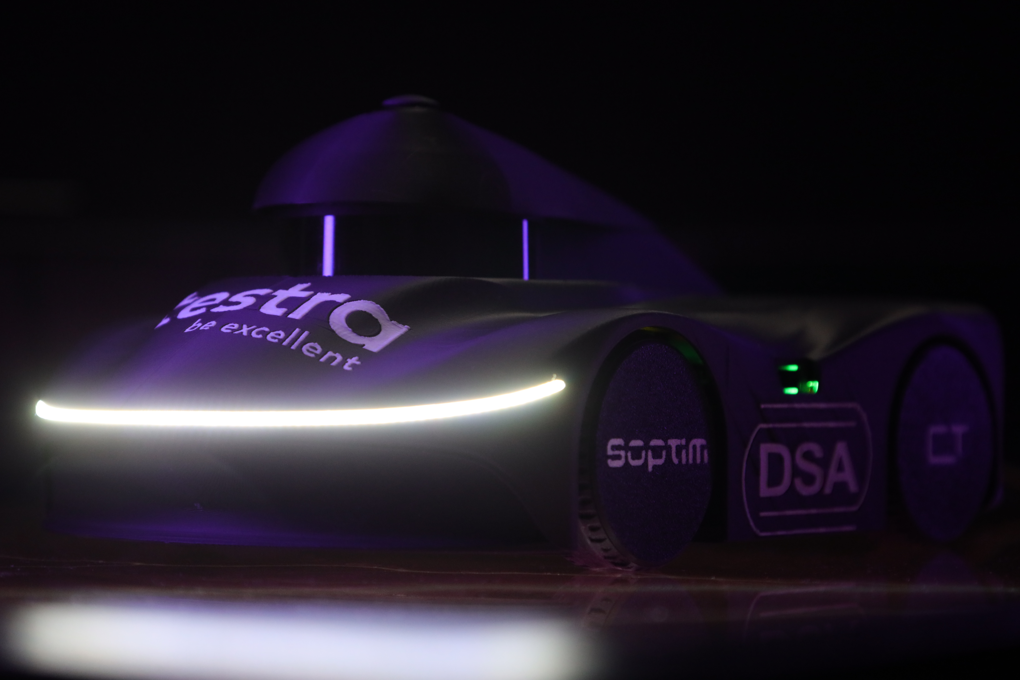
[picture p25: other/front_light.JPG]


The rear and front LED-Bars are driven by an LED-Bridge located underneath the "hood" of the robot, that gets 
directly controlled by the Raspberry Pi using hardware pwm. Since we wanted to still be able to quickly and easily 
remove and put on the replaceable bodywork, basically making it hot-swappable, we added 4-pin pogo connectors to 
both the replaceable bodywork and the front of the chassis, that simply connect magnetically, so no cabling has to 
be managed when removing the bodywork.

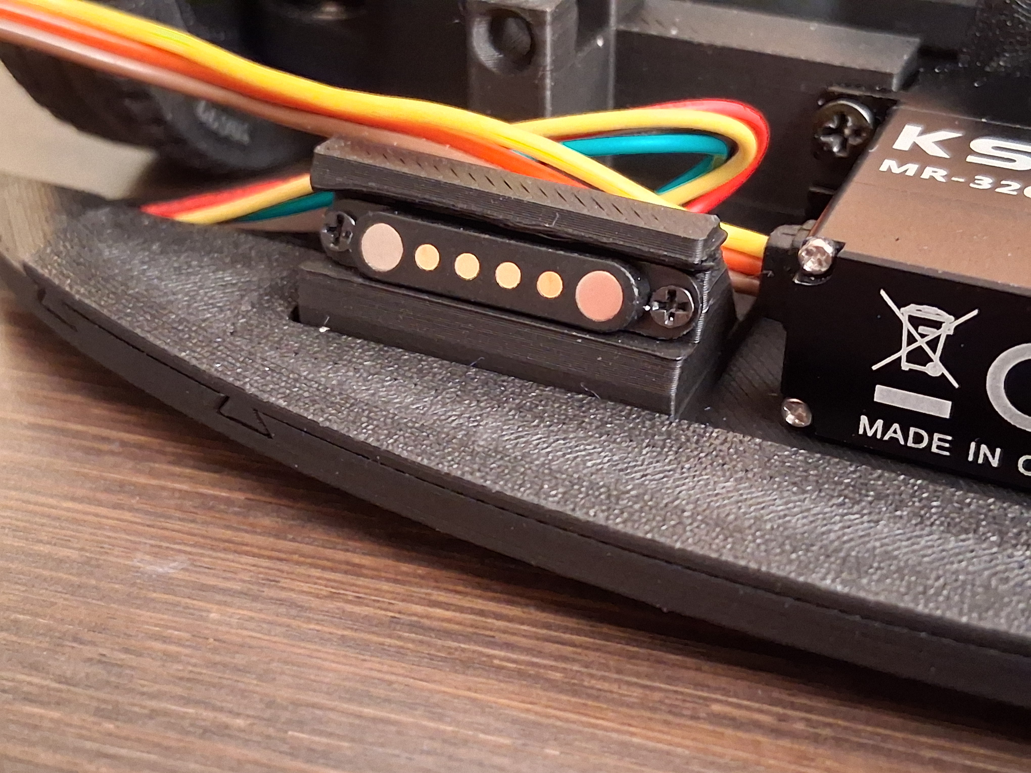
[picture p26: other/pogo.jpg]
> 
> 4-pin pogo connector on the chassis side for seamless bodywork hot-swap

### Vollständige Bill of Materials (BOM) 

Die folgendenden Materialien haben wir in unserem Roboter aktuell verbaut:

| Was | Anzahl | Link |
|---|:---:|---|
| Raspberry Pi 5 – 8 GB | 1 | https://www.raspberrypi.com/products/raspberry-pi-5/ |
| Slamtec RPlidar S3 | 1 | https://www.slamtec.com/en/S3 |
| Pi 5 Active Cooler | 1 | https://www.amazon.de/dp/B0CNVDF2MC?ref=ppx_yo2ov_dt_b_fed_asin_title&th=1 |
| IMX219 Camera Sensor | 1 | https://eckstein-shop.de/WaveshareIMX219-200Camera2C200C2B0FOV2CApplicableforJetsonNano |
| Arducam LN010 Lens | 1 | https://www.welectron.com/Arducam-LN010-M12-Mount-076mm-Focal-Length-Camera-Lens-M32076M20 |
| Adafruit BNO085 | 1 | https://learn.adafruit.com/adafruit-9-dof-orientation-imu-fusion-breakout-bno085/overview |
| 1000 rpm DC Drive Motor | 1 | https://www.amazon.de/dp/B09LHCYB2D?ref=ppx_yo2ov_dt_b_fed_asin_title |
| DRV8871 Motor Bridge | 1 | https://www.ti.com/product/de-de/DRV8871 |
| 128 GB Micro SD Card | 1 | https://www.amazon.de/dp/B09X7DNF6G?ref=ppx_yo2ov_dt_b_fed_asin_title&th=1 |
| Custom Mainboard | 1 | see chapter 2 |
| Step Down Buck Converter (3A) | 1 | https://www.amazon.de/-/en/dp/B0823P6PW6?ref_=ppx_hzsearch_conn_dt_b_fed_asin_title_1 |
| Step Down Buck Converter (5A) | 1 | https://www.amazon.de/dp/B07VQCXDTC?ref=ppx_yo2ov_dt_b_fed_asin_title&th=1 |
| JST PH 6P Cable (10 cm) | 1 | https://www.taja-elektronik.de/Kabel-mit-zwei-JST-PH-Buchsen-6-polig-10-cm-AWG-24-UL1571 |
| LED Bridge (MX1508 Driver) | 1 | https://www.roboter-bausatz.de/p/mx1508-dc-motor-treiber-modul-ln298n-1.5a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 |
| Magnetic Pogo 4P connector Pair | 1 | https://de.aliexpress.com/item/1005006525401310.html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 |
| COB LED Filament (Red) | 1 | https://de.aliexpress.com/item/1005009477275962.html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 |
| COB LED Filament (White) | 1 | https://de.aliexpress.com/item/1005009477275962.html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 |
| Custom Bridge PCB | 1 | see chapter 2 |
| High Flow Cooling Fan | 2 | https://www.reichelt.de/de/de/shop/produkt/luefter_5_vdc_25x25x6mm_serie_mc-397636 |
| MR105ZZ Deep Groove Bearings | 4 | https://www.amazon.de/dp/B0894JY8RK?ref=ppx_yo2ov_dt_b_fed_asin_title&th=1 |
| SCY 16101 Deep Groove Bearings | 2 | https://www.amazon.de/dp/B0CQ581Y4J?ref=ppx_yo2ov_dt_b_fed_asin_title |
| KST MR320 Steering Servo | 1 | https://www.kst-servo-shop.de/KST-MR320-V2.0-1800-5.5kg.cmat7.4V/KST-1303 |
| Steering Tie Rod | 1 | https://www.amazon.de/dp/B08XMLJCHN?ref=ppx_yo2ov_dt_b_fed_asin_title |
| Steering Wheel Hubs | 1 | https://www.amazon.de/dp/B0867J88M2?ref=ppx_yo2ov_dt_b_fed_asin_title |
| 10 × 2 mm Circular magnets | 8 | https://www.amazon.co.uk/Magenesis-Magnets-Approx-Adhesive-Strength/dp/B06X977K8L?th=1 |
| 43.2 × 14 Rubber Tire (Lego 30699) | 4 | https://www.bricklink.com/v2/catalog/catalogitem.page?P=30699&ccName=6182551#T=C&C=11 |
| Camera FPC Adapter-Cable | 1 | https://www.welectron.com/Raspberry-Pi-Zero-Kamera-FPC-Kabel-150mm |
| M 1.4 – M 2.5 Countersunk Screw Set | 1 | https://www.amazon.de/-/en/dp/B0DRCV6Q83?ref_=ppx_hzsearch_conn_dt_b_fed_asin_title_1&th=1 |
| M 3 Countersunk Phillips Screw Set | 1 | https://www.amazon.de/-/en/dp/B0DQCSK3QR?ref_=ppx_hzsearch_conn_dt_b_fed_asin_title_6&th=1 |
| 24 AWG Wires (20 cm) | 4 | https://www.amazon.co.uk/Youmile-Silicone-Stranded-Electrical-Assortment/dp/B08DTF88KT |
| LP-E6 Battery | 2 | https://www.amazon.co.uk/DSTE-Li-Ion-Battery-Compatible-MarkIII/dp/B092QNQF63 |
| TS05042 Axle for Ball Diff | 1 | https://www.rc-kleinkram.de/detail/index/sArticle/57135 |
| 16 teeth drive sprocket | 1 | https://www.amazon.de/dp/B0CYC7VYSZ?ref=ppx_yo2ov_dt_b_fed_asin_title |

# Obstacle Mangement

For the obstacle Challenge we divide the game field into 4 discreet zones, which are basically just one side of the 
game field. For 
example, 
the zone marked green in this picture 
would be the south zone:

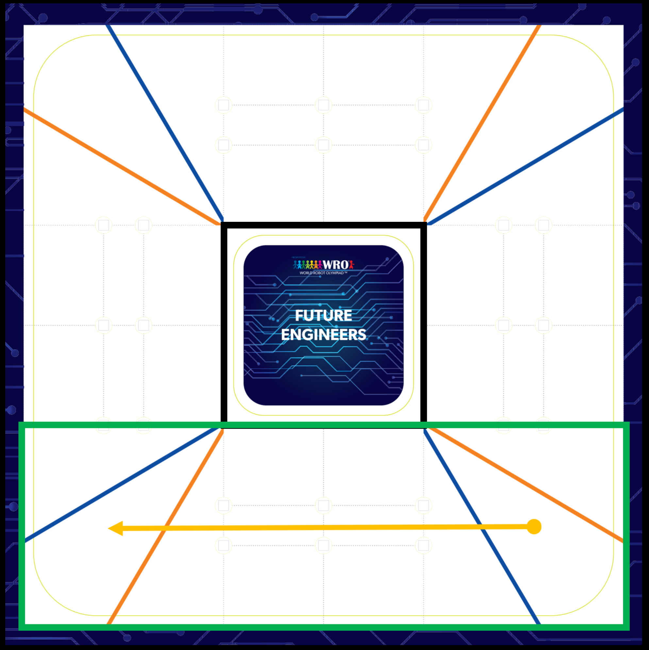
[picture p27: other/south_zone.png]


The basic idea behind this is to treat every zone as its individual challenge, but standardizing the zone driving up 
to lining up through a 90° turn for the following zone, so that the challenge becomes a lot simpler as a smaller 
part in each zone

## Code Architecture

But before we dive deeper into how we concretely approach the obstacle challenge using these zones, let's take a 
look at the general structure and architecture of our code.

We'll start with the fundamentals: Our Pi 5 is running Ubuntu 24.04 LTS as the OS. Why not Raspbian OS? Because of 
ROS, the Robot Operating System.

ROS is a widely used set of communication standards and libraries that is applied in all kinds of robotics applications.
So ROS isn't actually a real OS but more like a really handy toolbox when it comes to anything robotics related, 
because it is such a widely accepted standard, that for example all big sensor manufacturers naturally provide you 
with a ROS driver.

From there on its basically plug and play (most of the time 😅). For example, say tomorrow a new Lidar sensor comes 
out from a different manufacturer with whom we've never worked before. Instead of having to port or rewrite our code 
to a new standard, we could literally download the driver, compile it, plug in the new sensor and our code wouldn't 
even notice anything changed.

But besides that, the communication standards provided by ROS also just make the communication between the differen 
components of the code much easier.

So it's all well and good? Well kind of. You see, ROS is only natively supported on Ubuntu (which is why we use it) 
but Ubuntu doesn't have full support for all the cool features of the Pi 5 yet. So it is a trade off.

For us the two most noticeable issues with compatibility are:
- CSI camera interface support (the standard FPC Camera connector on the Pi)
- Hardware PWM support (which the Pi 5 normally has 4 channels of)

These two features are crucial to our application because we need the best and fastest connection to the camera we 
can get and especially for the steering servo but also for the drivetrain and Lighting, we need hardware PWM.

The Camera issued could be solved by simply compiling libcamera (a standard linux camera driver) from source and 
then accessing the frames manually using our specially developed CamManager class (src/cammanager.py).

The hardware PWM was a bit more tricky: We could not find a pre-made way that would work on our system, so we had to 
write our own custom hardware PWM driver, that does everything manually (src/hw_pwm.py). That took a bit of time, 
but when we eventually got it to work we could finally implement our entire code structure which looks like this:

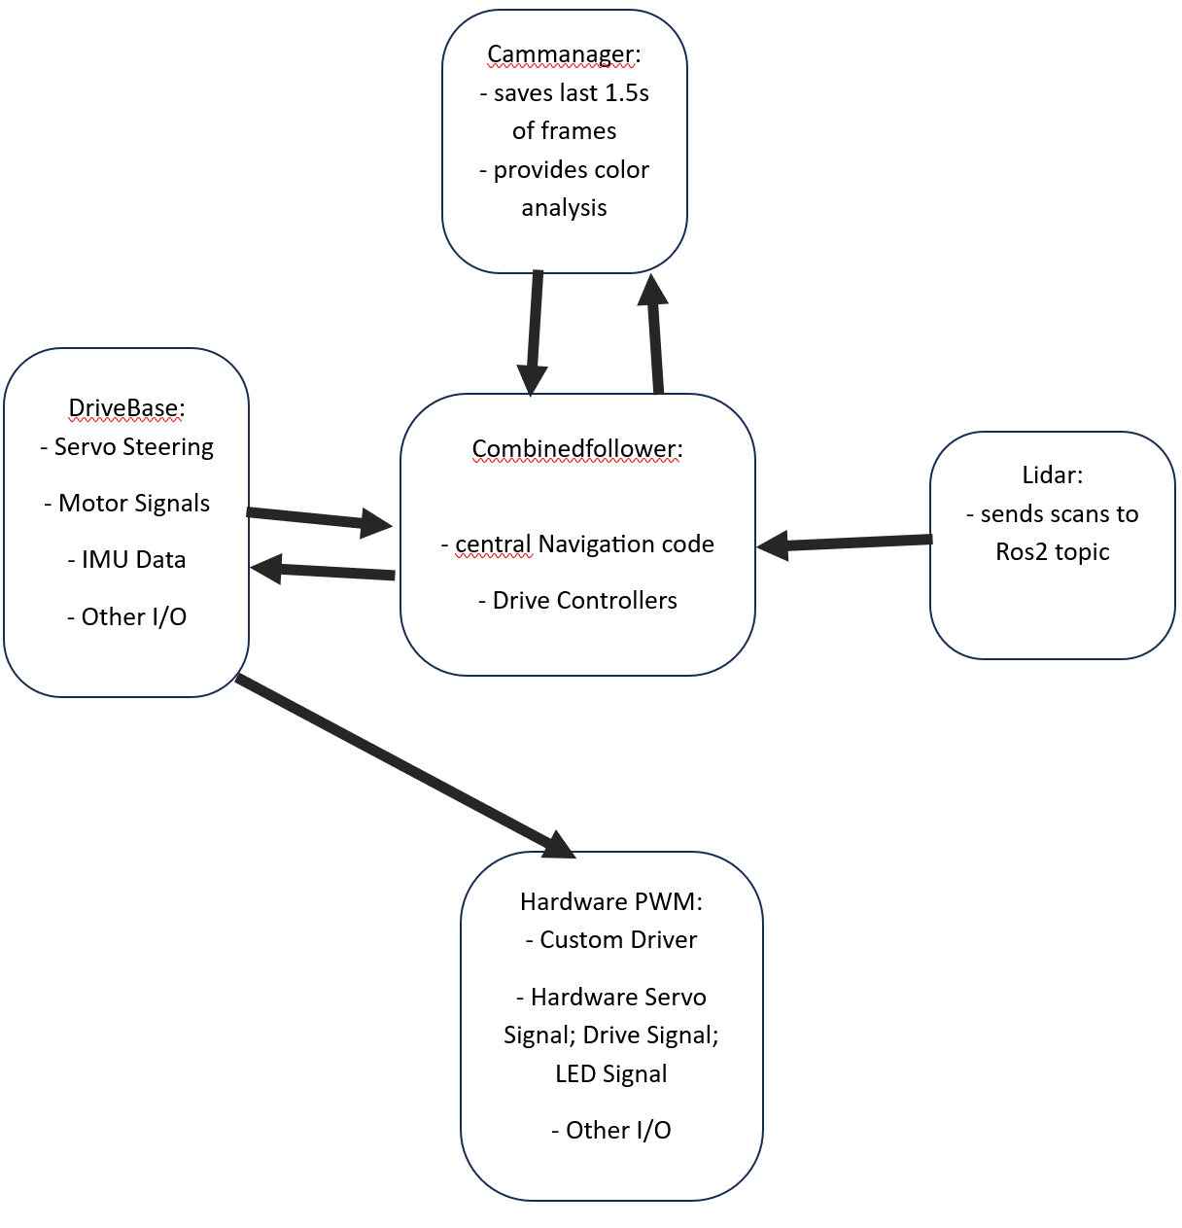
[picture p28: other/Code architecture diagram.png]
Code architecture diagram.png


### Code Structure

Now well quickly go through what the individual components do:

#### CamMananger

Our cammanager spins up a thread as soon as it is initiated, that constantly saves all incoming frames from the 
camera into a fast deque buffer. Whenever we want to analyze a specific angle on from a specific timestamp our 
cammanager also exposes the analyze_patch_at_time method that can provide us with just that.

#### DriveBase

The Drivebase is our interface to work with anything IO or driving related. It also facilitates communication with 
the IMU. The drivebase spawns a control loop threat upon startup, that constantly checks the state of the drivetrain 
and can do very precise adjustments to the speed based on the encoder readings. If the Drivebase gets any Output 
related commands via methods like set_steering() or brake(), it directly controls our hardware pwm driver to make 
sure, the components react as expected.

#### Lidar

The lidar is the only piece of code not provided by us, but rather the manufacturer who has provided a driver that 
calls a callback method in our main navigation script "Combinedfollower" that basically does the entire heavy lifting.

#### CombinedFollower

That is because the CombinedFollower is our main control code. It gets all the inputs from all the sensors, plans 
our navigation on a high level but also controls the actual following of this path on a low level as well. It also 
keeps Track of the current state and is responsible for the safety mechanisms like our collision avoidance system.

And with that out of the way we can actually dive into the actual driving now.

## Zone Flow

In each of the zones our robot always follows the exact same steps to complete it in a predictable manner:

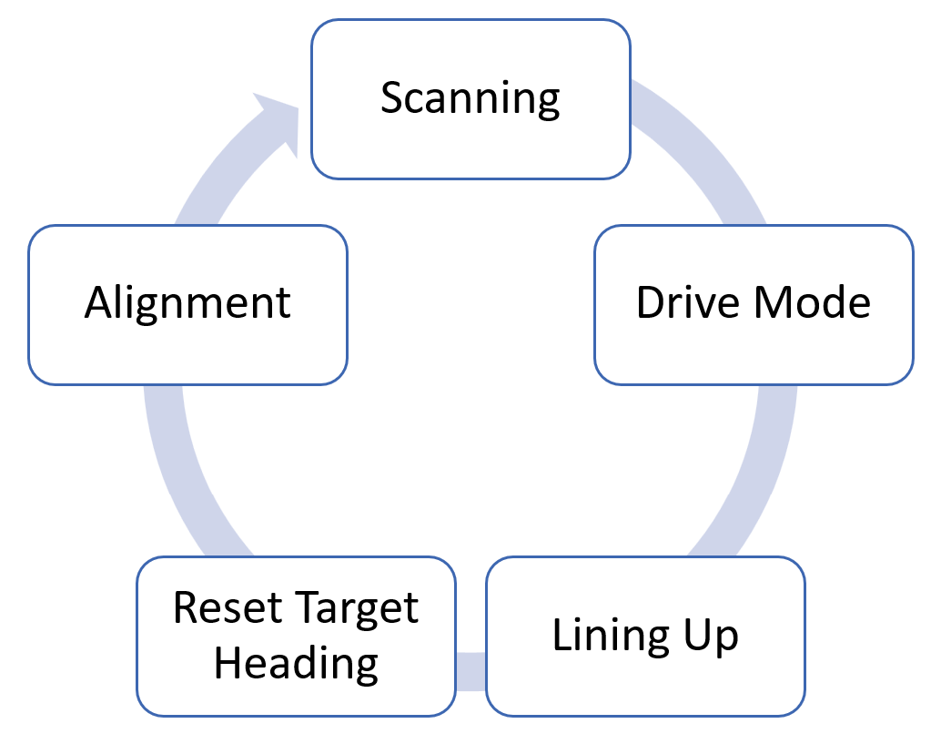
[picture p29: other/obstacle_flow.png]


Now we'll go through an example of a zone to get an understanding of what all these zones do.

### Scanning
In this phase the robot is standing still. It is already aligned for the upcoming zone, but before it starts driving 
it tries to detect the obstacles that will be present in this zone.

It does this by first detecting the obstacles in each Lidar scan it receives by forming clusters of measurement points 
that 
are 
close to each other. Since the obstacles are at least ~35 cm away from any walls and only 5 cm wide, they are pretty 
easy to filter out. Still, just to be safe, the absolute position of the obstacles is also checked to tell whether 
it really is an obstacle.

If an obstacle is detected, the CamManager gets asked for the frame that was taken closest to the lidar timestamp 
and gives back the color of the patch in question. If no color is detected, the obstacle is not marked for now, but 
if it is, it gets appended to the detected list, which the robot would use in the following Drive mode for 
navigation. This Code does exactly the steps described above:

            # Clustering of LiDAR points in angular sector
            clusters = []
            cur = []
            bad = 0
            mask = self.cached_sector_mask
            for i in range(N):
                r = ranges[i]
                in_sector = bool(mask[i])
                valid_r = math.isfinite(r) and (r <= self.max_range)
                last_r = ranges[cur[-1]] if cur else None
                jump_ok = True
                if cur and valid_r and abs(r - last_r) >= self.cluster_thresh:
                    jump_ok = False
                if (not in_sector) or (not valid_r) or (cur and not jump_ok):
                    bad += 1
                    if bad >= 12 and cur:
                        clusters.append(cur)
                        cur = []
                        bad = 0
                else:
                    bad = 0
                    cur.append(i)
            if cur:
                clusters.append(cur)

            # Precompute direction vector of the corridor
            measure_rad_env = math.radians(self.target_heading % 360.0)
            Lx = math.cos(measure_rad_env)
            Ly = math.sin(measure_rad_env)

            # Compute distance to the wall on the side
            if self.direction == "CLOCK":
                start_deg = 85 - yaw_synced_deg + self.target_heading
                end_deg   = 95 - yaw_synced_deg + self.target_heading
                d_side = sample_range(start_deg, end_deg)
            else:
                start_deg = 265 - yaw_synced_deg + self.target_heading
                end_deg   = 275 - yaw_synced_deg + self.target_heading
                d_side = sample_range(start_deg, end_deg)

            # For each cluster compute geometry and ask CamManager for color
            for c in clusters:
                if len(c) < 2:
                    continue
                rs = ranges[c]
                angs_c = angs[c]
                r_avg = float(rs.mean())
                mid_rad = (angs_c[0] + angs_c[-1]) / 2.0

                obs_global_rad = math.radians(yaw) + mid_rad
                Ox = math.cos(obs_global_rad) * r_avg
                Oy = math.sin(obs_global_rad) * r_avg
                raw_perp = (Lx * Oy - Ly * Ox)
                if self.direction == "CLOCK":
                    new_perp = d_side - raw_perp
                else:
                    new_perp = d_side + raw_perp
                parallel = (Lx * Ox + Ly * Oy)

                # Check whether obstacle lies within the corridor band
                if not (self.perp_min_dist <= new_perp <= self.perp_max_dist):
                    continue

                # Check cluster width
                width_m = abs(angs_c[-1] - angs_c[0]) * r_avg
                if not (self.min_diameter <= width_m <= self.max_diameter):
                    self.get_logger().info(
                        f"Dropped inside corridor for width {width_m:.3f}m "
                        f"(cluster at mid {math.degrees(mid_rad) % 360:.1f}°)"
                    )
                    continue

                # Build a timestamp for camera manager using LiDAR time
                ref_wall_s = time.time()
                ref_mono_ns = time.monotonic_ns()
                offset_ns = ref_mono_ns - int(ref_wall_s * 1_000_000_000)
                off_ts = (lidar_ts * 1_000_000_000) + offset_ns

                # Query CamManager for color label and HSV at the patch position
                bfre = time.monotonic_ns()
                label, used_ts, age_ms, h, s, v = self.mgr.analyze_patch_at_time(
                    off_ts + (30 * 1_000_000),
                    (178.2 + (math.degrees(mid_rad) % 360)),
                    2.22 / r_avg,
                    preview=False
                )

### Drive Mode

As soon as the scanning of the obstacles is successfully completed, the code switches into drive mode and starts 
actually navigating around the obstacles. The previously shown obstacle detection still runs though, in order to 
make sure no obstacles are missed, even if the scanning phase might not have picked them up.

While drive mode is active, this controller code is responsible for keeping the robot perfectly on track:

        # --- OBS mode: DRIVE state (main obstacle tracking) ---
        elif self.mode == "OBS" and self.obs_status == "DRIVE":
            # In DRIVE we are following a colored obstacle and using it to keep
            # a certain distance from the wall. Here we compute steering and speed.

            # Allow larger steering range while driving around obstacles
            self.max_left = math.radians(90)
            self.max_right = math.radians(90)
            turn_limiter_enable = True

            # Current "drive mode" is based on which obstacle we track and how far it is
            d_mode = self.obs_drive_state or ""
            # Direction of the lap (CLOCK = right, COUNTER = left)
            d_dir = self.direction

            # If we are in the special section 12 lap stop phase we may force
            # a specific drive mode that was saved earlier.
            if self.save_status != "":
                print("mode to: " + str(self.save_status))
                d_mode = self.save_status

            # Decide which side distance we want based on color and "near/far" state.
            # These values were tuned so the robot takes nice lines around the pylons.
            if (d_dir == "CLOCK" and d_mode == "RED_FAR") or (d_dir == "COUNTER" and d_mode == "GREEN_FAR"):
                target_distance = 0.741
            elif (d_dir == "CLOCK" and d_mode == "RED_CLOSE") or (d_dir == "COUNTER" and d_mode == "GREEN_CLOSE"):
                target_distance = 0.62
            elif (d_dir == "CLOCK" and d_mode == "GREEN_FAR") or (d_dir == "COUNTER" and d_mode == "RED_FAR"):
                target_distance = 0.38
            elif (d_dir == "CLOCK" and d_mode == "GREEN_CLOSE") or (d_dir == "COUNTER" and d_mode == "RED_CLOSE"):
                # In some sections we want a slightly different offset again
                if self.section_count % 4 == 0:
                    target_distance = 0.38
                else:
                    target_distance = 0.238
            else:
                # Fallback when no clear mode is set
                target_distance = 0.5

            # Measure actual distance to the wall on the side we follow.
            # We sample a small angular window relative to the current heading.
            if self.direction == "CLOCK":
                # Following wall on the left
                start_deg = 85 - yaw_synced_deg + self.target_heading
                end_deg   = 95 - yaw_synced_deg + self.target_heading
                d_l = sample_range(start_deg, end_deg)
                # Positive lateral_error means we are too far away from the wall
                lateral_error = target_distance - d_l
            else:
                # Following wall on the right
                start_deg = 265 - yaw_synced_deg + self.target_heading
                end_deg   = 275 - yaw_synced_deg + self.target_heading
                d_l = sample_range(start_deg, end_deg)
                # Sign is flipped when following the right side
                lateral_error = -(target_distance - d_l)

            # If we are in a mode with a larger target distance, we refine lateral_error
            # by also checking more forward looking angles. This helps in open areas.
            if target_distance > 0.48:
                if self.direction == "COUNTER":
                    # Looking slightly ahead and behind on left side
                    start_deg = 72 - yaw_synced_deg + self.target_heading
                    end_deg   = 75 - yaw_synced_deg + self.target_heading
                    d_d1 = sample_range(start_deg, end_deg)
                    start_deg = 98 - yaw_synced_deg + self.target_heading
                    end_deg   = 101 - yaw_synced_deg + self.target_heading
                    d_d2 = sample_range(start_deg, end_deg)
                else:
                    # Looking slightly ahead and behind on right side
                    start_deg = 259 - yaw_synced_deg + self.target_heading
                    end_deg   = 262 - yaw_synced_deg + self.target_heading
                    d_d1 = sample_range(start_deg, end_deg)
                    start_deg = 280 - yaw_synced_deg + self.target_heading
                    end_deg   = 283 - yaw_synced_deg + self.target_heading
                    d_d2 = sample_range(start_deg, end_deg)

                # "leer" will represent a corrected virtual side distance
                leer = 0

                # Depending on how far we want to be, use a different trigger distance
                if target_distance > 0.67:
                    limit = 0.42
                else:
                    limit = 0.55

                # If the near forward/backward beams are closer than this limit,
                # we compute a new effective side distance "leer" and use that
                # instead to adjust lateral_error.
                if d_d1 < limit:
                    leer = 0.94 - d_d1
                    if self.direction == "CLOCK":
                        lateral_error = target_distance - leer
                    else:
                        lateral_error = -(target_distance - leer)
                elif d_d2 < limit:
                    leer = 0.94 - d_d2
                    if self.direction == "CLOCK":
                        lateral_error = target_distance - leer
                    else:
                        lateral_error = -(target_distance - leer)

            # Log raw side distance for debugging
            self.get_logger().debug("dl_: %.2f" % d_l)

            # Smooth lateral error so that sudden jumps in the LiDAR
            # do not cause very abrupt steering.
            if self.last_d is None:
                self.last_d = lateral_error
            else:
                # If the new error differs a lot from the previous one,
                # move only half way to the new value.
                if abs(lateral_error - self.last_d) > 0.09:
                    lateral_error = self.last_d + (lateral_error - self.last_d) / 2
                self.last_d = lateral_error

            # Heading error: how far the current yaw is from the target heading
            heading_error = -(self.target_heading - yaw_current_deg)

            # Compute base steering value depending on how large lateral_error is
            # and whether we are in a parking sequence.
            if self.park_active and abs(lateral_error) > 0.05 and self.direction == "COUNTER":
                # Strong lateral control when parking and going counterclockwise
                steer_nominal = (1.5 * lateral_error)
            elif self.park_active:
                # In parking mode mix heading and lateral control
                steer_nominal = 0.022 * heading_error + 1.3 * lateral_error
            elif abs(lateral_error) > 0.12:
                # If we are far off from desired distance, use strong lateral correction
                steer_nominal = (1.5 * lateral_error)
            elif abs(lateral_error) > 0.06:
                # Medium deviation, mix a bit of heading and lateral control
                steer_nominal = (0.005 * heading_error + 1.3 * lateral_error)
            else:
                # Close to target distance. Use softer combined control.
                # One special case for GREEN_CLOSE / RED_CLOSE in some sections.
                if (
                    (d_dir == "CLOCK" and d_mode == "GREEN_CLOSE")
                    or (d_dir == "COUNTER" and d_mode == "RED_CLOSE")
                ) and self.section_count % 4 == 0:
                    steer_nominal = 0.022 * heading_error + 1.1 * lateral_error
                else:
                    steer_nominal = 0.022 * heading_error + 1.1 * lateral_error

            abs_st = abs(steer_nominal)
            print("abs steer: " + str(abs_st))

            # Choose speed based on how much we are steering and other conditions.
            # The idea: the more we steer, the slower we go, to keep things stable.
            if abs_st >= 0.6:
                # Very strong steering → slow down
                speed_steer = 0.40
            if abs(lateral_error) > 0.18:
                # If lateral error is really big, override and use this speed
                speed_steer = 0.46
            elif abs(heading_error) > 8:
                # If heading error is large, also slow down
                speed_steer = 0.36
            elif abs_st <= 0.12:
                # Almost straight ahead, allow max speed
                speed_steer = self.speed_max
            else:
                # Middle region, interpolate a speed, then override with tuned value
                frac = (abs_st - 0.2) / (0.6 - 0.1)
                speed_steer = self.speed_min + (0.51 - self.speed_min) * frac
                # Final tuned constant value
                speed_steer = 0.52

            # Also limit speed based on free space in front of the robot.
            start_f = 357 - yaw_synced_deg + self.target_heading
            end_f   = 360 - yaw_synced_deg + self.target_heading
            d_front = sample_range(start_f, end_f)

            # If there is a lot of space ahead, we can go faster.
            # If it is very close, we slow down.
            if d_front >= 1.2:
                speed_front = self.speed_max
            elif d_front <= 0.3:
                speed_front = self.speed_min
            else:
                frac2 = (d_front) / (1.1 - 0.0)
                speed_front = self.speed_min + (0.62 - self.speed_min) * frac2

            # Combine steering-based speed and front-distance-based speed
            speed = min(speed_steer, speed_front)
            steer = steer_nominal

            # Extra logic: if there is almost nothing in front and we are steering little
            # and no obstacle is currently selected, then we consider the obstacle passed
            # and move to PASSED state after a short braking phase.
            if d_front < 0.94 and abs(steer_nominal) < 0.22 and selected is None:
                speed = 0.1
                if self.stop_times < 4:
                    self.stop_times += 1
                else:
                    self.stop_times = 0
                    self.obs_status = "PASSED"
            else:
                self.stop_times = 0

            # If collision avoidance CAU (caution) is active, clamp speed further.
            if self.coll_avd == "CAU":
                speed = min(speed, self.speed_min + 0.04)

            # In section 12 we always slow down more for safety and timing reasons.
            if self.section_count == 12:
                speed = min(speed, 0.3)

            # Apply steering limits based on target heading and current yaw
            if turn_limiter_enable:
                steer = self.apply_turn_limiter(
                    steer,
                    math.radians(self.target_heading),
                    yaw_current_rad
                )
                # Global scaling of steering to make overall steering softer
                steer = 0.78 * steer

            # Final clamp of steering command
            steer = max(-0.8, min(0.8, steer))
            print("drive speed set: " + str(speed))

### Linig Up

After drive mode has passed all obstacles in a zone it starts lining up for the next one. It tries to line up 
perfectly with the next zone by doing a 90° reversing turn (for reversing turn see _turn_control in combinedfollower). 

### Resetting Target Heading & Alignment

After completing the turn, the algorithm resets the target heading to the new "stright line" direction of the 
upcoming zone. So its basically just and offset by 90°. These 90° however are purely IMU based, and the gyroscope 
can have a drift. In order to mitigate the risk of IMU drift-caused inaccuracies, right after resetting the target 
heading, our code uses multiple lidar scans to detect the outer wall on the other side of the game field and align 
itself perfectly perpendicular to that wall:

        # --- ALIGN mode handling ---
        if self.obs_status == "ALIGN":
            # In ALIGN state we want to correct our target_heading so that it matches
            # the real wall direction seen by the LiDAR.
            # We do not drive here, we only collect a number of scans and then
            # compute the best estimate of the wall orientation.

            # Store the current scan (ranges and angles) in a list.
            # Each entry is a tuple (rg, ag) where:
            #   rg = array of distances for this scan
            #   ag = array of angles for this scan
            self.align_scans.append((ranges, angs))

            # Wait until we have collected enough scans to get a stable result.
            if len(self.align_scans) >= self.align_max:
                pts_all = []  # will hold "good" wall points from all scans

                # Loop over all stored scans
                for rg, ag in self.align_scans:
                    # Compute angles relative to the robot "side" direction.
                    # We wrap angles to the interval [-pi, +pi] to make comparison easier.
                    rel = ((ag + math.pi) % (2 * math.pi)) - math.pi

                    # Build a mask that selects only points within a small angular range
                    # around the side direction (for example plus or minus 12 degrees).
                    mask = np.abs(rel) <= math.radians(self.align_sector_half_deg)

                    # Find indices of points that lie inside this angular band.
                    idxs = np.where(mask)[0]

                    if idxs.size:
                        # From those indices keep only points with:
                        # - finite distance (no "inf" or NaN)
                        # - distance larger than 2.35 m (so we focus on the far wall and not close clutter)
                        valid = [i for i in idxs if math.isfinite(rg[i]) and rg[i] > 2.35]

                        if valid:
                            # Convert valid polar points (range, angle) into Cartesian coordinates (x, y).
                            xs = rg[valid] * np.cos(ag[valid])
                            ys = rg[valid] * np.sin(ag[valid])

                            # Stack x and y into an array of 2D points: shape (N, 2)
                            pts = np.vstack((xs, ys)).T

                            # Compute the median point of this set. This approximates the center
                            # of the wall points for this scan.
                            medx, medy = np.median(pts[:, 0]), np.median(pts[:, 1])

                            # For each point compute its distance to the median point.
                            dists = np.hypot(pts[:, 0] - medx, pts[:, 1] - medy)

                            # Keep only points that are not too far from the median (within 0.15 m).
                            # This removes outliers and noise.
                            inliers = pts[dists < 0.15]

                            # If we still have at least 5 points, treat them as good wall points
                            # from this individual scan and store them.
                            if inliers.shape[0] >= 5:
                                pts_all.append(inliers)

                # After processing all stored scans check if we have any wall points at all.
                if not pts_all:
                    self.get_logger().warning("ALIGN: no valid wall points in ±12° sector over scans")
                else:
                    # Combine all inliers from all scans into one big array.
                    all_pts = np.vstack(pts_all)

                    # If the total number of points is still very small, the estimate would be noisy.
                    if all_pts.shape[0] < 50:
                        self.get_logger().warning(f"ALIGN: too few total points ({all_pts.shape[0]})")
                    else:
                        # Compute the centroid (mean x and y) of all wall points.
                        centroid = all_pts.mean(axis=0)

                        # Distance of each point to the centroid.
                        d_all = np.hypot(all_pts[:, 0] - centroid[0], all_pts[:, 1] - centroid[1])

                        # Median distance of all points from the centroid.
                        med = np.median(d_all)

                        # Threshold for removing far outliers.
                        # It is set to the larger of:
                        #   0.2 m
                        #   1.5 times the median distance
                        thresh = max(0.2, 1.5 * med)

                        # Keep only points closer than this threshold.
                        inliers = all_pts[d_all < thresh]

                        # If we lose too many points, alignment may be unreliable.
                        if inliers.shape[0] < 40:
                            self.get_logger().warning(
                                f"ALIGN: too few inliers after prune ({inliers.shape[0]})"
                            )
                        else:
                            # We now have a clean set of wall points.
                            # Next we use a simple PCA to find the orientation of the wall.

                            # Shift points so that their mean is at the origin.
                            pts0 = inliers - inliers.mean(axis=0)

                            # Compute covariance matrix of the centered points.
                            cov = np.dot(pts0.T, pts0) / pts0.shape[0]

                            # Compute eigenvalues and eigenvectors of the covariance matrix.
                            eigvals, eigvecs = np.linalg.eig(cov)

                            # Take the eigenvector with the largest eigenvalue.
                            # This eigenvector points along the main direction of the wall.
                            v = eigvecs[:, np.argmax(eigvals)]

                            # Convert the wall direction from vector components into an angle in degrees.
                            wall_ang = math.degrees(math.atan2(v[1], v[0])) % 360.0

                            # Compute orientation relative to robot coordinate system.
                            # Here 270 degrees is the expected direction of the wall for this side.
                            rel = wall_ang - 270
                            if rel > 180:
                                # Wrap from (180, 360) back into (-180, 0) for easier interpretation.
                                rel -= 360.0

                            # Apply a manual offset to account for system calibration.
                            rel_adj = rel - self.align_offset_deg

                            # theoretical is what we currently assume is correct for target_heading.
                            theoretical = self.target_heading

                            # imu_error is how far the IMU yaw currently is from that theoretical heading.
                            imu_error = yaw_current_deg - theoretical

                            # error_align expresses how much the measured wall direction differs from expected.
                            error_align = rel_adj

                            # The total drift is a combination of IMU drift and wall alignment error.
                            drift = imu_error + error_align

                            # If the drift is not too large (within ±8 degrees),
                            # we trust the wall measurement and adjust our target_heading by this drift.
                            if abs(drift) <= 8.0:
                                new_target = theoretical + drift
                                self.get_logger().info(
                                    f"ALIGN: wall_ang={wall_ang:.2f}°, rel={rel:.2f}°, rel_adj={rel_adj:.2f}°, "
                                    f"theoretical={theoretical:.2f}°, imu={yaw_current_deg:.2f}°, "
                                    f"imu_error={imu_error:.2f}°, error_align={error_align:.2f}°, "
                                    f"new_target={new_target:.2f}"
                                )
                                # Update target_heading so that future driving uses the corrected heading.
                                self.target_heading = new_target
                            else:
                                # If the drift is too large we consider the measurement unsafe
                                # and keep the old theoretical heading.
                                self.get_logger().info(
                                    f"ALIGN: wall_ang={wall_ang:.2f}°, rel={rel:.2f}°, rel_adj={rel_adj:.2f}°, "
                                    f"theoretical={theoretical:.2f}°, imu={yaw_current_deg:.2f}°, "
                                    f"imu_error={imu_error:.2f}°, error_align={error_align:.2f}°"
                                )
                                self.get_logger().warning(
                                    f"ALIGN: alignment error too large ({error_align:.2f}°), "
                                    f"using theoretical {theoretical:.2f}°"
                                )
                                self.target_heading = theoretical

After alignment has been completed successfully, the code goes back into Scanning mode to begin the new zone.

### Parking

For leaving and entering the parking lot, our robot uses its big steering angle to do both in one go in a 
preprogrammed motion that can best be explained through our obstacle challenge video.

When parking, the robot enters a special controller mode in the Drive mode, where it creeps forward as slowly as 
possible until it reaches one of multiple predefined positions with and accuracy of a few millimeters:

            # Parking forward distance based on park_active and direction
            if self.park_active:
                self.obs_status = "DRIVE"
                if self.direction == "COUNTER":
                    start_deg = 280 - yaw_synced_deg + self.target_heading
                    end_deg   = 283 - yaw_synced_deg + self.target_heading
                    d_d2 = sample_range(start_deg, end_deg)
                    start_f = 355 - yaw_synced_deg + self.target_heading
                    end_f   = 360 - yaw_synced_deg + self.target_heading
                    d_front = sample_range(start_f, end_f)
                    if d_front <= 0.960 and d_front >= 0.885:
                        if self.stops_times < 3:
                            self.stops_times += 1
                            self.drive_base.brake(1)
                            speed_front = 0
                            print("holding parksss")
                        else:
                            self.stops_times = 0
                            self.obs_status = "PARK_TURN"
                            print("holding park")
                            speed_front = 0
                    elif d_front <= 1.9:
                        speed_front = 0.101
                    else:
                        frac2 = (d_front - 0.1) / (1.7 - 0.0)
                        speed_front = 0.22
                else:
                    start_f = 0 - yaw_synced_deg + self.target_heading
                    end_f   = 5 - yaw_synced_deg + self.target_heading
                    d_front = sample_range(start_f, end_f)
                    if d_front <= 1.588 and d_front >= 1.125:
                        print("close")
                        if self.stops_times < 3:
                            self.stops_times += 1
                            self.drive_base.brake(1)
                            speed_front = 0
                            print("holding parksss")
                        else:
                            self.stops_times = 0
                            self.obs_status = "PARK_TURN"
                            print("holding park")
                            speed_front = 0
                    elif d_front <= 2.1:
                        speed_front = 0.101
                    else:
                        frac2 = (d_front - 0.1) / (1.7 - 0.0)
                        speed_front = self.speed_min + (self.speed_max - self.speed_min) * frac2
                speed = min(speed_steer, speed_front)

After reaching the predefined position the robot performs two 90° turns to place itself precisely into the parking lot.

## Open Challenge

To determine the driving direction in the open challenge, the robot analyzes multiple lidar scans to determine which 
side of him sees the front barrier and which the rear. It then proceeds to a open challenge specific drive mode.

### Driving
For the open challenge we use a dynamic wall following algorithm with corner detection based speed control:

        # --- FREE mode controllers (wall following without obstacles) ---
        elif self.mode == "FREE" and self.direction == "CLOCK":
            # We are in "FREE" mode and driving clockwise around the track.
            # In this mode we just follow the wall without looking at colored obstacles.

            # Distance in meters at which we start treating something as a "corner"
            threshold = 0.67
            corner = 0.0

            # Take LiDAR samples in three regions:
            #  - "lefts": roughly to the left side of the robot
            #  - "fronts": directly in front
            #  - "backs": partly left/back, used to stabilize the estimate
            lefts  = [sample(math.radians(a)) for a in range(28, 60)]
            fronts = [sample(math.radians(a)) for a in range(4, 6)]
            backs  = [sample(math.radians(a)) for a in range(33, 62)]

            # Filter out invalid readings (None or zero)
            fin_l = [d for d in lefts if d]
            fin_f = [d for d in fronts if d]
            fin_b = [d for d in backs if d]

            # Average distances in each region.
            # If no valid points, fall back to a very large distance.
            d_l = sum(fin_l) / len(fin_l) if fin_l else float('inf')  # distance to wall on the left
            d_f = sum(fin_f) / len(fin_f) if fin_f else float('inf')  # distance straight ahead

            # If something is closer than the threshold in front,
            # we interpret it as a corner and compute how "deep" the corner is.
            if d_f < threshold:
                corner = threshold - d_f

            # Compute an error term that combines:
            #  - how close we are to a corner
            #  - how far the left distance is from the desired distance (0.54 m)
            # The signs and factors are tuned experimentally.
            error = -0.5 * (1.3 * corner + 1 * (0.54 - d_l))

            # Convert the error into a steering angle "ang".
            # Larger error means more steering.
            ang = self.kp_lateral * error

            # Limit the maximum steering based on how much free space we have in front:
            #  - if there is a lot of space (d_f large) we allow stronger steering
            #  - if it is tighter, we limit the steering more
            cap = 0.6 if d_f >= 1.05 else min(0.1 + 0.3 * d_f, 0.6)
            # Apply that cap only for positive steering angles
            ang = min(ang, cap) if ang >= 0 else ang

            # Add extra steering when we are in a corner.
            # This makes the robot turn into the corner more aggressively.
            ang -= corner * 1.77

            # If we are very close to something in front, turn even more.
            if d_f <= 0.32:
                ang -= 0.12

            # Compute a speed reduction factor based on the magnitude of the error.
            #  - If error is small, factor is close to 1 (faster).
            #  - If error is large, factor is closer to 0.72 (slower).
            if error != 0:
                factor = max(0.72, min(1.0, 0.13 / abs(0.9 * error)))
            else:
                factor = 1.0

            # Final speed in FREE mode:
            # base maximum speed (v_max_free_r) multiplied by the safety factor.
            speed = self.v_max_free_r * factor

            # For clockwise driving, steering is inverted here so that
            # positive "ang" turns the robot in the correct physical direction.
            steer = -ang

Finally, the robot detects the completion of the 3 open challenge laps using its imu and stops after a predefined 
distance inside the final section.

# Videos
Our videos with explanations about the runs can be found here:

Open Challenge:
https://www.youtube.com/watch?v=OKg4hAgMCkw

Obstacle Challenge:
https://www.youtube.com/watch?v=ECM8k0c84Ro

# Github utilization
In work on our project for the International final, we decided to separate our working repo from this documentation 
repo, since using our design approach we often create temporary structures that would just clutter the 
documentation repo with no real benefit. 

Our internal working repo can be found here: https://github.com/carltron-aero/src

During development towards Singapore we used our internal working repo whenever any new developments were made in 
order for everyone to be on the same page. We also used features like using different branches to pursue multiple 
design approaches at the same time in order to compare the outcomes without interfering with each other.

# Organizational Engagement – Founding a Non-Profit
## Transitioning from School to University
As we started into our first season of competing at the World Robot Olympiad we competed as a private team. We knew 
from the beginning that this won’t be an option for further competitions on a bigger stage like nationals or internationals. That’s why we started early to search for a organization from which we can use the already existing structures that are needed for international competition. Just coming out of school this was quite hard for us as we spent many years competing at similar Competitions while being backed by our old school. However now we graduated and do not have this option anymore. So, we started searching for said organizations at our university campus. We first approached a smaller university robotics club that seemed promising and we hoped that we could join it and compete as a team of this robotics club. However, our ideas were too far apart, and the discussed club was very focused on other fields of robotics and there was no way that we could build our project as we imagined it. We also approached a couple of chairs/faculties at RWTH Aachen University but also quickly realized that competing under a chair would mean a large amount of bureaucracy and would leave us with less flexibility. This left us with the in our eyes best option for us: Founding a non profit organisation as a student initiative.
## Getting started
After finally deciding to found a nonprofit organization, we first had no idea how such a process works. That’s why 
we searched for help wherever we could find any. We consulted other university organizations that have already been 
through this process, the central assistance office of our university, assistance offices provided by the city and 
many more organizations. After we had a picture of what we needed to find a nonprofit we started to work on the 
founding process itself as there are a lot of requirements that have to be met to get registered as a non profit 
organisation in Germany by the court.  
##Founding a nonprofit organisation
To start of we first had to write the clubs statues that have to meet certain requirements. This is important not 
only to be a credited organisation by the court, but also to become a nonprofit. For that you have to additionally 
apply with the financial authorities. After writing the club statues, we sent them to a likeminded organisation that 
offered help in the beginning and also to the financial authorities for them to check for any errors or mistakes 
that could cost us the certification as a nonprofit. Luckily, we were thoroughly enough so we could hold our founding assembly. For that the club needs at least seven members. From those at least half of them have to be students of RWTH Aachen University for the club to be eligible for becoming accredited to be a student initiative, for what you have to apply separately as well. So, we asked fellow students, other WRO participants from our city and our families to join our club and be part of the founding assembly.  And so, on the 22nd September the Aachen Engineering & Robotics Organization (soon to be e.V. (registered association)) was founded. If you think the work is done now, you are terribly mistaken. Now the struggle with the authorities only begins. First, we had to take all our founding documents including the signatures, addresses and consent forms of all founding members to a notary so he can apply the club at court. Finding a notary that could complete this quickly as we were hoping to have the organization standing until we attend the international final today was also not easy. After we met with the notary we chose, he told us that the process of accreditation with the court could take up to 4 month which was a minor setback for us but luckily organisations are able to operate from after the founding assembly with limited privileges. The next step for us was to also get accredited by the University as a student initiative. For that we needed a professor to be the patron which we found in a professor who also works in similar fields and was willing to support our project. The accreditation by the university went fast and we are now already a student initiative at RWTH Aachen University. The application to be a nonprofit with the financial authorities is pretty much the hardest of all as the application forms require you to know a lot about finances and tax law in advance, which we don’t. However, we started by contacting the office of the authority directly and are receiving help from them as we are still in this application process. After we finish that which will only take about a week when we get back to Germany we will just have to wait for the authorities to reach out back to us and then after about five month we will finally be a fully baked nonprofit organization student initiative. 
## Future Plans
We not only founded the Aachen Engineering & Robotics Organization with the goal in mind to participate in the WRO. As our club statues state we want to support education and exchange of information. We plan to implement this by offering workshops at school and will do this for the first time actually here in Singapore as we will visit the German European School Singapore later next week. Also one of our club members has organized the last regional WRO competition in our hometown Aachen and we are planning to support this with our organization next year and the following years. Lastly we want to offer the exact supportive environment and organization we searched for in the beginning of this whole process. Other students should be able to join our club and implement their ideas and projects without having to go through this process like we did. Opportunities like developing and working on projects like the WRO present a whole different layer of education and a variety that one does not find in the regular curriculum. 
## Reflection on Building a Nonprofit Organization
The process of founding and building a nonprofit organization was undoubtedly a hard one which required a lot of work, and it definitely has not gone as planned all the time. There were setbacks along the way that we did not expect, and we could have done things differently and also better at times but that you can not know in the beginning. After all the experience we take away from this is invaluable. One always grows with his tasks and we surely grew a lot in this time. From learning about all the different processes described above to connecting with new people and taking responsibility for the organization.

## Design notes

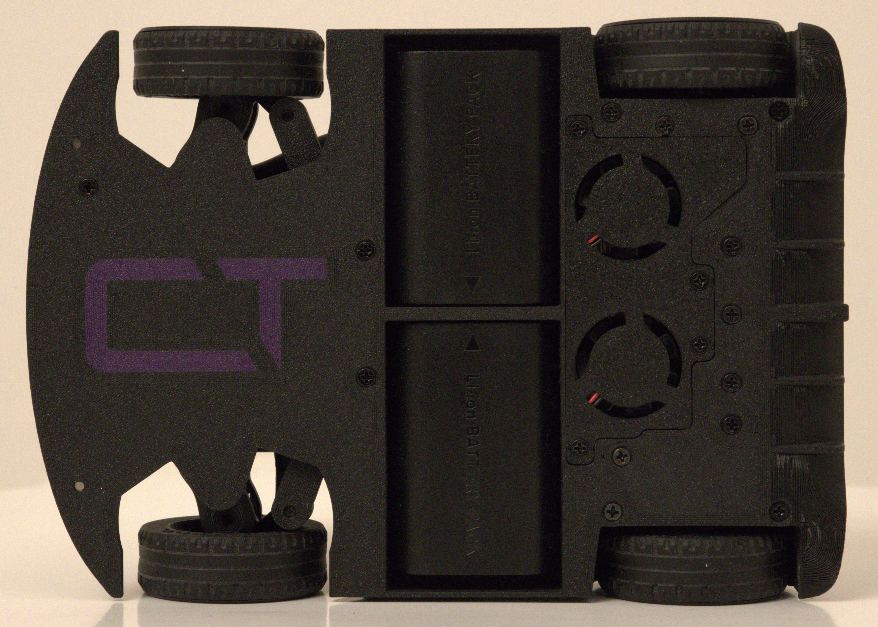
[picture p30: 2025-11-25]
v-photos/bottom_view.jpg

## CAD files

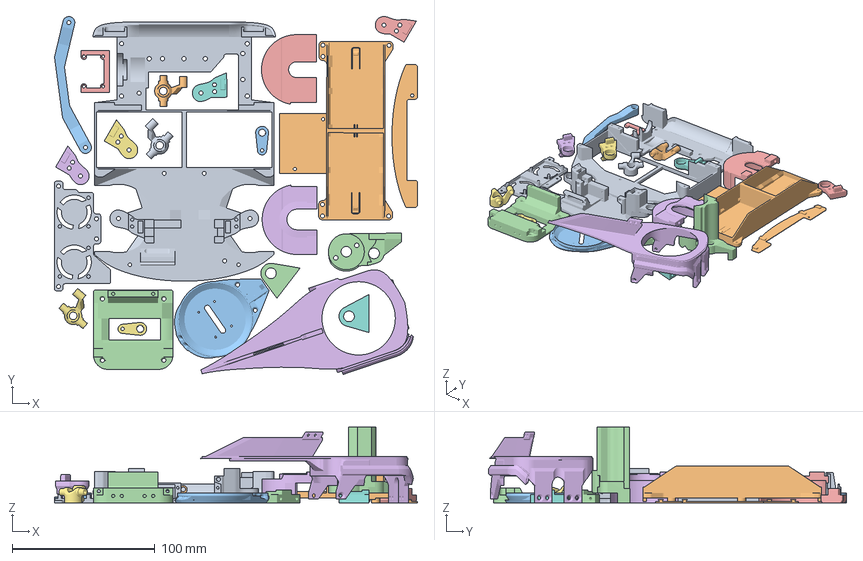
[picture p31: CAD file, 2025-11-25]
models/All small Parts.3mf
254.3 x 250.5 x 53.1 mm
Main Chassus (66).stl
Main Chassus - Part 1 (75).stl
Main Chassus - Part 10 (8).stl
Main Chassus - Part 200 (1).stl
Main Chassus - Part 203 (2).stl
Main Chassus - Part 204 (3).stl
Main Chassus - Part 271 (2).stl x 2
Main Chassus - Part 266.stl x 2
Main Chassus - Part 264.stl
Main Chassus - Part 270 (1).stl x 2
Main Chassus - Part 267.stl
Main Chassus - Part 3 (16).stl
Main Chassus - Part 12 (4).stl
Main Chassus - Part 8 (8).stl
KST MR320 - Part 3 (10).stl x 2
Main Chassus - Part 201 (3).stl x 2
Main Chassus - Part 206 (4).stl
Main Chassus - Part 268 (1).stl

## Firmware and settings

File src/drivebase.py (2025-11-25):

#!/usr/bin/env python3
"""
DriveBase

This module controls a drive base on a Raspberry Pi 5 (Ubuntu 24.04)
using:
- Hardware PWM (via hw_pwm module) for steering servo + H-bridge drive + front LED
- Software PWM (gpiozero.PWMLED) for rear/red/green LEDs
- A wheel encoder (GPIO20) to measure speed and distance
- An IMU (BNO08X via I2C) to read yaw; provides wrapped and continuous yaw (+ history buffer)
- A mode-based speed controller (COAST / BRAKE_TO_STOP / SPEED) using a simple PI loop


Highlights:
- Speed controller uses encoder feedback and a PI controller.
- If the measured speed glitches high beyond a **known physical max** (1.6 m/s),
  it is clamped to **0** for that tick to prevent the controller from fighting a phantom reading.
- Going to target speed 0 ⇒ immediate COAST (no residual torque).
- Target speed sign flip (e.g., + to -) ⇒ full BRAKE until stopped, then ramp to new target.

Test section at the bottom:
- Demonstrates coast on zero target and brake-then-reverse behavior.
- Continuously prints yaw (wrapped + continuous), controller mode, speed, and target.
"""

import os
import time
import math
import threading
from collections import deque
import bisect

# --- try to import HW PWM module ---
# Prefer `hw_pwm.py`, but fall back to a local filename `hw-pwm.py` if needed.
try:
    import hw_pwm as hpwm  # preferred filename: hw_pwm.py
except ModuleNotFoundError:
    import importlib.util
    here = os.path.dirname(os.path.abspath(__file__))
    candidate = os.path.join(here, "hw-pwm.py")
    if not os.path.exists(candidate):
        raise
    spec = importlib.util.spec_from_file_location("hpwm", candidate)
    hpwm = importlib.util.module_from_spec(spec)
    spec.loader.exec_module(hpwm)

from gpiozero import DigitalInputDevice, PWMLED, Button

# ===== IMU (BNO08x) =====
# Uses the "game rotation vector" (gravity-free) for stable yaw.
import board
import busio
import adafruit_bno08x
from adafruit_bno08x.i2c import BNO08X_I2C

# =======================
# DriveBase configuration
# =======================
# Encoder
ENCODER_PIN_A = 20
PULSES_PER_REV = 104
GEAR_MOTOR = 16
GEAR_WHEEL = 60
GEAR_RATIO = GEAR_MOTOR / GEAR_WHEEL
WHEEL_DIAMETER_M = 0.0432
WHEEL_CIRCUM_M = math.pi * WHEEL_DIAMETER_M

# Control loop (PI controller) — tuned by you
CTRL_HZ = 90.0
KP = 1.62
KI = 2.5
INT_LIMIT = 1.0

# Software-PWM LED pins (rear + status LEDs)
REAR_LED_PIN = 11
RED_LED_PIN  = 5
GREEN_LED_PIN = 6
LED_PWM_FREQ = 1000

# Switch input (pull-up)
SWITCH_PIN = 4

# IMU streaming
IMU_HZ = 200.0
IMU_BUFFER_SECONDS = 1.5
IMU_BUFFER_SIZE = int(IMU_HZ * IMU_BUFFER_SECONDS) + 4
MAX_YAW_RATE_DPS = 720.0                 # For sanity checks if desired in future
_MAX_DELTA_PER_SAMPLE = MAX_YAW_RATE_DPS / IMU_HZ  # (unused but documented)

def _now():
    """Monotonic time helper (seconds)."""
    return time.monotonic()

def _log(msg: str):
    """Small timestamped logger to stdout."""
    print(f"[{_now():.3f}] {msg}")

def _quat_to_euler_deg(x, y, z, w):
    """
    Convert quaternion -> Euler angles in degrees.
    Returns (roll, pitch, yaw) in deg, yaw ∈ (-180..+180].
    """
    sinr_cosp = 2.0 * (w * x + y * z)
    cosr_cosp = 1.0 - 2.0 * (x * x + y * y)
    roll = math.atan2(sinr_cosp, cosr_cosp)

    sinp = 2.0 * (w * y - z * x)
    if abs(sinp) >= 1:
        pitch = math.copysign(math.pi / 2, sinp)
    else:
        pitch = math.asin(sinp)

    siny_cosp = 2.0 * (w * z + x * y)
    cosy_cosp = 1.0 - 2.0 * (y * y + z * z)
    yaw = math.atan2(siny_cosp, cosy_cosp)

    return math.degrees(roll), math.degrees(pitch), math.degrees(yaw)

class DriveBase:
    """
    High-level robot base:
      - Steering (hpwm)
      - Open-loop drive & braking/coast (hpwm)
      - Closed-loop speed in m/s via encoder on GPIO20
      - Signed distance (m)
      - LEDs: Front(HW PWM ch1) mirrors → GREEN(GPIO6); Rear(SW PWM GPIO11) mirrors → RED(GPIO5)
      - Switch (GPIO4, pull-up): get_switch_state()
      - IMU (BNO08x I2C): current yaw + 1.5 s yaw buffer (≥150 Hz)
        * get_current_yaw()              -> latest wrapped yaw (relative to last zero)
        * get_yaw_at(t_monotonic)        -> nearest wrapped yaw in buffer (relative to last zero)
        * get_continuous_yaw()           -> unwrapped yaw (…,-360,0,360,…), zeroed
        * set_yaw_zero()                 -> define current heading as 0° baseline
    """

    def __init__(self):
        # --- hardware setup (one-time) ---
        # Steering servo, LED (HW PWM), and drive H-bridge channels
        hpwm.setup_pwm_servo()
        hpwm.setup_pwm_led()
        hpwm.setup_pwm_drive()

        # SW-PWM LEDs: rear brightness and two status LEDs
        self.rear_led  = PWMLED(REAR_LED_PIN, frequency=LED_PWM_FREQ)
        self.red_led   = PWMLED(RED_LED_PIN,  frequency=LED_PWM_FREQ)
        self.green_led = PWMLED(GREEN_LED_PIN, frequency=LED_PWM_FREQ)

        # Switch input (active low if pulled to GND)
        self.switch = Button(SWITCH_PIN, pull_up=True)

        # Encoder: count pulses for speed/distance
        self._enc = DigitalInputDevice(ENCODER_PIN_A, pull_up=True)
        self._pulse_count = 0
        self._pulse_lock = threading.Lock()
        self._enc.when_activated = self._on_pulse

        # Kinematics state
        self._rpm_motor = 0.0
        self._mps = 0.0               # Signed speed at the wheel (m/s)
        self._distance_m = 0.0        # Signed distance (m); + forward, - backward
        self._last_tick = _now()

        # Drive state
        self._target_speed_mps = 0.0  # Commanded target speed (m/s)
        self._integrator = 0.0        # PI controller integral
        self._last_drive_dir = 0.0    # -1 (reverse), 0 (idle), +1 (forward)
        self._ctrl_running = False
        this_thread = None
        self._ctrl_thread = this_thread

        # Mode state machine for safe transitions around 0 speed
        #   COAST -> no torque (immediate on target=0)
        #   BRAKE_TO_STOP -> full brake to stop before reversing
        #   SPEED -> normal PI control
        self._mode = "COAST"
        self._pending_target_mps = 0.0
        self._stop_counter = 0
        self._STOP_EPS_MPS = 0.02
        self._STOP_CONFIRM_TICKS = 3

        # IMU: I2C + BNO08x in "game rotation vector" mode (reduced gravity influence)
        i2c = busio.I2C(board.SCL, board.SDA, frequency=400000)
        self._bno = BNO08X_I2C(i2c)
        self._bno.enable_feature(adafruit_bno08x.BNO_REPORT_GAME_ROTATION_VECTOR)

        # IMU yaw buffer (wrapped yaws relative to current zero)
        self._yaw_buf = deque(maxlen=IMU_BUFFER_SIZE)  # stores (timestamp, yaw_deg)
        self._yaw_lock = threading.Lock()

        # Store both raw and bias-adjusted wrapped yaw
        self._yaw_wrapped_raw = 0.0    # last raw fused yaw (-180..180)
        self._current_yaw = 0.0        # wrapped yaw AFTER bias (relative to zero)

        # Continuous yaw (unwrapped) based on bias-adjusted values
        self._yaw_prev = None          # previous adjusted wrapped yaw
        self._yaw_continuous = 0.0
        self._yaw_zero = 0.0           # kept at 0 when zeroing via bias
        self._yaw_bias = 0.0           # raw fused yaw subtracted so heading becomes 0

        # IMU streaming thread + "first sample ready" signal
        self._imu_running = True
        self._imu_ready = threading.Event()
        self._imu_thread = threading.Thread(target=self._imu_loop, daemon=True)
        self._imu_thread.start()

        # Wait for a real IMU sample, then zero heading to that orientation
        if not self._imu_ready.wait(timeout=0.5):
            _log("Warning: IMU did not produce a sample within 0.5 s")
        self.set_yaw_zero()

        _log("DriveBase initialized (control + IMU threads ready)")

    # =====================
    # Encoder pulse handler
    # =====================
    def _on_pulse(self):
        """ISR-like callback for each encoder A rising edge."""
        with self._pulse_lock:
            self._pulse_count += 1

    # =========
    # Switch API
    # =========
    def get_switch_state(self) -> bool:
        """
        Returns True when the switch input is active (pressed), else False.
        Pull-up input → pressed == pulled low to ground.
        """
        return self.switch.is_pressed

    # ===============
    # Public controls
    # ===============
    def set_steering(self, normalized: float):
        """
        Steering command: normalized ∈ [-1, +1], mapped to servo angle by hw_pwm.
        """
        hpwm.set_steering_angle(normalized)

    def set_drive_power(self, throttle: float):
        """
        Open-loop drive power: throttle ∈ [-1, +1].
        Disables speed control (sets mode based on zero/non-zero).
        """
        self._target_speed_mps = 0.0
        hpwm.set_drive(throttle)
        self._last_drive_dir = 0.0 if throttle == 0 else (1.0 if throttle > 0 else -1.0)
        self._mode = "SPEED" if throttle != 0 else "COAST"

    def brake(self, level: float):
        """Active braking (both H-bridge sides driven). level ∈ [0..1]."""
        self._target_speed_mps = 0.0
        hpwm.brake(level)

    def coast(self):
        """Coast (outputs off)."""
        self._target_speed_mps = 0.0
        hpwm.coast()
        self._last_drive_dir = 0.0
        self._mode = "COAST"

    # --- LEDs ---
    def set_front_led(self, level: float):
        """
        Front LED is HW-PWM (channel 1) and mirrors onto GREEN LED (GPIO6) via SW-PWM.
        level ∈ [0..1]
        """
        hpwm.set_led(level)
        lvl = max(0.0, min(1.0, float(level)))
        self.green_led.value = lvl

    def set_rear_led(self, level: float):
        """
        Rear LED (GPIO11) and RED LED (GPIO5) are SW-PWM and always equal to each other.
        level ∈ [0..1]
        """
        lvl = max(0.0, min(1.0, float(level)))
        self.rear_led.value = lvl
        self.red_led.value = lvl

    # --- Closed-loop speed control (m/s) ---
    def set_target_speed(self, mps: float):
        """
        Set desired wheel speed in m/s.

        Special cases:
        - If target is ~0 → immediate COAST (no torque, integrator cleared).
        - If sign flips across 0 while moving → BRAKE_TO_STOP first, then adopt new target.
        """
        # print("req speed: " + str(mps))
        new = float(mps)

        # Immediate coast on zero target
        if abs(new) < 1e-9:
            self._target_speed_mps = 0.0
            self._integrator = 0.0
            self._pending_target_mps = 0.0
            self._mode = "COAST"
            hpwm.coast()
            self._last_drive_dir = 0.0
            return

        # If sign flips across zero (and we're actually moving), brake hard to stop first
        if self._mps * new < 0 and abs(self._mps) > self._STOP_EPS_MPS:
            self._pending_target_mps = new
            self._target_speed_mps = 0.0
            self._integrator = 0.0
            self._mode = "BRAKE_TO_STOP"
            self._stop_counter = 0
            hpwm.brake(1.0)
            return

        # Normal: enter SPEED mode and track with PI
        self._pending_target_mps = 0.0
        self._target_speed_mps = new
        self._mode = "SPEED"
        # print("speed mode: " + str(self._mode))

    def get_speed(self) -> float:
        """Current signed wheel speed estimate (m/s)."""
        return self._mps

    def get_distance(self) -> float:
        """Accumulated signed distance (m). Positive forward, negative reverse."""
        return self._distance_m

    # ==========
    # IMU getters
    # ==========
    def get_current_yaw(self) -> float:
        """
        Latest wrapped yaw (deg, -180..+180) relative to the last zero.
        This is bias-adjusted so that set_yaw_zero() defines current heading as 0°.
        """
        return self._current_yaw

    def get_continuous_yaw(self) -> float:
        """
        Unwrapped yaw (deg) that continues beyond ±180 (…, -360, 0, +360, …),
        relative to the last zero.
        """
        with self._yaw_lock:
            return self._yaw_continuous - self._yaw_zero  # yaw_zero kept at 0 on zero()

    def set_yaw_zero(self):
        """
        Define the current IMU heading as 0° baseline by:
        - Capturing the latest RAW fused yaw as a bias
        - Resetting unwrap state and continuous yaw accumulator
        """
        with self._yaw_lock:
            self._yaw_bias = self._yaw_wrapped_raw
            self._yaw_prev = 0.0
            self._yaw_continuous = 0.0
            self._yaw_zero = 0.0
            self._current_yaw = 0.0  # immediate user feedback

    def get_yaw_at(self, t_monotonic: float) -> float:
        """
        Return the wrapped yaw (relative to zero) closest in time to the given
        monotonic timestamp (seconds). Useful to align IMU samples with other events.
        """
        with self._yaw_lock:
            if not self._yaw_buf:
                return self._current_yaw
            ts = [pair[0] for pair in self._yaw_buf]
            idx = bisect.bisect_left(ts, t_monotonic)
            if idx <= 0:
                return self._yaw_buf[0][1]
            if idx >= len(ts):
                return self._yaw_buf[-1][1]
            t0, y0 = self._yaw_buf[idx-1]
            t1, y1 = self._yaw_buf[idx]
            return y0 if abs(t_monotonic - t0) <= abs(t1 - t_monotonic) else y1

    # ================
    # Control loop impl
    # ================
    def start(self):
        """Start the high-rate control loop thread."""
        if self._ctrl_running:
            return
        self._ctrl_running = True
        self._ctrl_thread = threading.Thread(target=self._ctrl_loop, daemon=True)
        self._ctrl_thread.start()
        _log("Control loop started")

    def stop(self):
        """Stop the control loop thread."""
        self._ctrl_running = False
        if self._ctrl_thread:
            self._ctrl_thread.join(timeout=1.0)
            self._ctrl_thread = None
        _log("Control loop stopped")

    def _ctrl_loop(self):
        """
        Main loop running at CTRL_HZ:
        - Converts encoder pulses → wheel speed (m/s) + signed distance
        - Applies mode logic (COAST, BRAKE_TO_STOP, SPEED)
        - In SPEED mode, runs PI controller to match _target_speed_mps
        - IMPORTANT GUARD: if |mps| > 1.6 (physically impossible here), set to 0 for this tick
          to reject encoder glitches that would destabilize the controller.
        """
        period = 1.0 / CTRL_HZ
        while self._ctrl_running:
            t0 = _now()

            # ----- Consume encoder pulses accumulated since last tick -----
            with self._pulse_lock:
                pulses = self._pulse_count
                self._pulse_count = 0

            # Time delta for this tick
            dt = t0 - self._last_tick
            if dt <= 0:
                dt = period
            self._last_tick = t0

            # ----- Kinematics from encoder -----
            pps = pulses / dt if dt > 0 else 0.0
            rpm_motor = (pps * 60.0) / PULSES_PER_REV
            wheel_rps = (rpm_motor / 60.0) * GEAR_RATIO
            mps_unsigned = wheel_rps * WHEEL_CIRCUM_M

            # Direction sign: last drive command OR target speed sign in SPEED mode
            sign = self._last_drive_dir
            if self._mode == "SPEED" and self._target_speed_mps != 0:
                sign = 1.0 if self._target_speed_mps > 0 else -1.0

            self._rpm_motor = rpm_motor
            self._mps = mps_unsigned * sign
            self._distance_m += (mps_unsigned * sign) * dt

            # ===== Drive mode handling =====
            if self._mode == "COAST":
                # Ensure coast (idempotent)
                hpwm.coast()
                self._last_drive_dir = 0.0

            elif self._mode == "BRAKE_TO_STOP":
                # Full brake until speed is near zero for a few ticks
                hpwm.brake(1.0)
                if abs(self._mps) < self._STOP_EPS_MPS:
                    self._stop_counter += 1
                else:
                    self._stop_counter = 0

                if self._stop_counter >= self._STOP_CONFIRM_TICKS:
                    # Transition to SPEED mode with pending target
                    self._integrator = 0.0
                    self._last_drive_dir = 0.0
                    self._target_speed_mps = self._pending_target_mps
                    self._pending_target_mps = 0.0
                    self._mode = "SPEED"

            else:  # "SPEED"
                if self._target_speed_mps == 0.0:
                    # Safety: shouldn't happen (set_target_speed(0) forces COAST)
                    hpwm.coast()
                    self._last_drive_dir = 0.0
                else:
                    # ---- Physical clamp against encoder glitches ----
                    if abs(self._mps) > 1.6:
                        # Known impossible on this platform → treat as 0 for this tick.
                        self._mps = 0

                    # ---- PI controller ----
                    error = self._target_speed_mps - self._mps
                    self._integrator += error * dt * KI
                    self._integrator = max(-INT_LIMIT, min(INT_LIMIT, self._integrator))
                    u = KP * error + self._integrator
                    u = max(-1.0, min(1.0, u))

                    # ---- Limit opposite torque vs target direction ----
                    # If PI asks for torque opposite to the *target* direction, cap it to ±0.1
                    desired_dir = 1.0 if self._target_speed_mps > 0 else -1.0
                    if u * desired_dir < 0:
                        if abs(u) > 0.1:
                            u = 0.0 if u > 0 else 0.0

                    hpwm.set_drive(u)
                    self._last_drive_dir = 0.0 if u == 0 else (1.0 if u > 0 else -1.0)

            # Maintain loop rate
            elapsed = _now() - t0
            to_sleep = period - elapsed
            if to_sleep > 0:
                time.sleep(to_sleep)

    # ================
    # IMU streamer impl
    # ================
    def _imu_loop(self):
        """
        IMU thread at IMU_HZ:
        - Reads quaternion from BNO08X game rotation vector
        - Converts to wrapped yaw (deg)
        - Applies bias (set_yaw_zero) so current heading is 0°
        - Maintains a 1.5s buffer of wrapped yaw samples
        - Builds a continuous yaw (unwrapped) by accumulating small wrapped deltas
        """
        period = 1.0 / IMU_HZ
        while self._imu_running:
            t0 = _now()
            try:
                qi, qj, qk, qr = self._bno.game_quaternion
                _, _, yaw_wrapped = _quat_to_euler_deg(qi, qj, qk, qr)

                with self._yaw_lock:
                    # keep raw for future biasing
                    self._yaw_wrapped_raw = yaw_wrapped

                    # apply current bias to get RELATIVE wrapped yaw in (-180,180]
                    yaw_rel = ((yaw_wrapped - self._yaw_bias + 180.0) % 360.0) - 180.0

                    # update current yaw and add to buffer
                    self._current_yaw = yaw_rel
                    self._yaw_buf.append((t0, yaw_rel))

                    # first-sample signal
                    if not hasattr(self, "_imu_ready") or self._imu_ready is None:
                        pass
                    else:
                        self._imu_ready.set()

                    # Unwrap to continuous yaw on the relative values
                    if self._yaw_prev is None:
                        self._yaw_prev = yaw_rel
                        # continuous yaw was set to 0 on zeroing
                    else:
                        delta = (yaw_rel - self._yaw_prev + 180.0) % 360.0 - 180.0
                        self._yaw_continuous += delta
                        self._yaw_prev = yaw_rel

            except Exception as e:
                _log(f"IMU read error: {e}")

            elapsed = _now() - t0
            to_sleep = period - elapsed
            if to_sleep > 0:
                time.sleep(to_sleep)

    # ==========
    # Housekeeping
    # ==========
    def shutdown(self):
        """
        Gracefully stop threads and put hardware in a safe state.
        """
        try:
            self.stop()
            self._imu_running = False
            if self._imu_thread:
                self._imu_thread.join(timeout=1.0)
                self._imu_thread = None

            self.set_target_speed(0.0)
            self.set_drive_power(0.0)
            self.coast()
            self.set_front_led(0.0)
            self.set_rear_led(0.0)
            hpwm.cleanup_pwm_servo()
            for p in (hpwm.PWM1_PATH, hpwm.PWM2_PATH, hpwm.PWM3_PATH):
                try:
                    hpwm.write(f"{p}/enable", 0)
                except:
                    pass
        finally:
            _log("Shutdown complete")
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

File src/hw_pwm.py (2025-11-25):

#!/usr/bin/env python3
"""
hw_pwm

Low-level hardware-PWM control for Raspberry Pi 5 via sysfs (/sys/class/pwm).

Channels (on pwmchip0):
  0: Steering servo (50 Hz, RC pulses 0.5–2.5 ms)
  1: Front LED (0..1 duty) — high-rate dimming
  2: Drive reverse  (0..1 duty) — H-bridge leg
  3: Drive forward  (0..1 duty) — H-bridge leg

This module exposes:
  - setup_pwm_servo(), set_steering_angle(), cleanup_pwm_servo()
  - setup_pwm_led(),   set_led(level)
  - setup_pwm_drive(), set_drive(throttle), brake(level), coast()

"""

import os
import time

# === HW PWM CONFIGURATION ===
PWM_CHIP = 0  # pwmchip0

# Channel mapping:
# 0: Steering servo (50 Hz RC pulse)
# 1: LED (0..1)
# 2: Drive reverse  (0..1)
# 3: Drive forward  (0..1)

# Frequencies
SERVO_FREQ_HZ = 50
LED_FREQ_HZ   = 1000
DRIVE_FREQ_HZ = 20000

# Periods in nanoseconds (sysfs expects ns)
SERVO_PERIOD_NS = (1_000_000 // SERVO_FREQ_HZ) * 1000
LED_PERIOD_NS   = (1_000_000 // LED_FREQ_HZ)   * 1000
DRIVE_PERIOD_NS = (1_000_000 // DRIVE_FREQ_HZ) * 1000

# Servo pulse range (in microseconds)
MIN_PULSE_US = 500
MAX_PULSE_US = 2500
MIN_PULSE_NS = MIN_PULSE_US * 1000
MAX_PULSE_NS = MAX_PULSE_US * 1000

# === Paths ===
BASE_PATH   = f"/sys/class/pwm/pwmchip{PWM_CHIP}"
PWM0_PATH   = f"{BASE_PATH}/pwm0"  # Servo
PWM1_PATH   = f"{BASE_PATH}/pwm1"  # LED
PWM2_PATH   = f"{BASE_PATH}/pwm2"  # Drive reverse
PWM3_PATH   = f"{BASE_PATH}/pwm3"  # Drive forward

def write(path, value):
    """Write a stringified value to a sysfs file."""
    with open(path, "w") as f:
        f.write(str(value))

def ensure_exported(pwm_path, channel_index):
    """
    Ensure that /sys/class/pwm/pwmchipX/pwmY exists by exporting Y if missing.
    Small sleep gives the kernel time to create the node.
    """
    if not os.path.exists(pwm_path):
        write(f"{BASE_PATH}/export", channel_index)
        time.sleep(0.05)

def setup_channel(pwm_path, period_ns, initial_duty_ns=0):
    """
    Disable → set period → set duty → enable.
    NOTE: Uses the last character of pwm_path as channel index (0..3).
    """
    ensure_exported(pwm_path, int(pwm_path[-1]))  # uses last char (0..3)
    try: write(f"{pwm_path}/enable", 0)
    except: pass
    write(f"{pwm_path}/period", period_ns)
    write(f"{pwm_path}/duty_cycle", initial_duty_ns)
    write(f"{pwm_path}/enable", 1)

def set_fraction(pwm_path, period_ns, frac):
    """
    Set duty as a fraction (0..1) of the given period in ns.
    Clamped to [0,1].
    """
    x = max(0.0, min(1.0, float(frac)))
    duty_ns = int(period_ns * x)
    write(f"{pwm_path}/duty_cycle", duty_ns)

# === Servo (channel 0) ===
def angle_to_duty_ns(angle):
    """
    Map servo angle (0..180°) to duty in ns within [0.5ms .. 2.5ms].
    Input is clamped to [0,180].
    """
    angle = max(0, min(180, angle))
    return int(MIN_PULSE_NS + (MAX_PULSE_NS - MIN_PULSE_NS) * angle // 180)

def setup_pwm_servo():
    """Export & enable servo PWM at 50 Hz, and center the pulse (~1.5ms)."""
    setup_channel(PWM0_PATH, SERVO_PERIOD_NS, 1_500_000)  # center

def cleanup_pwm_servo():
    """Disable the servo channel (does not unexport)."""
    write(f"{PWM0_PATH}/enable", 0)

def set_steering_angle(normalized):
    """
    Steering command: normalized in [-1, +1].
    Mapped to 45°..135° (±45° around 90° center) and converted to RC pulse width.
    """
    x = max(-1.0, min(1.0, normalized))
    angle = 45.0 * x + 90.0
    angle = min(max(45, angle), 135)
    duty_ns = angle_to_duty_ns(angle)
    write(f"{PWM0_PATH}/duty_cycle", duty_ns)

# === LED (channel 1) ===
def setup_pwm_led():
    """Export & enable LED PWM at 1 kHz, duty = 0%."""
    setup_channel(PWM1_PATH, LED_PERIOD_NS, 0)

def set_led(level):
    """Set LED brightness as fraction (0..1)."""
    set_fraction(PWM1_PATH, LED_PERIOD_NS, level)

# === Drive (channels 2 & 3) ===
def setup_pwm_drive():
    """Export & enable both H-bridge legs at 20 kHz, duty = 0%."""
    setup_channel(PWM2_PATH, DRIVE_PERIOD_NS, 0)
    setup_channel(PWM3_PATH, DRIVE_PERIOD_NS, 0)

def set_drive(throttle):
    """
    Bidirectional drive:
      throttle ∈ [-1, +1]
        > 0 → forward leg (pwm3) gets |throttle|, reverse leg off
        < 0 → reverse leg (pwm2) gets |throttle|, forward leg off
        = 0 → both legs off (coast)
    """
    #print("Drive Power: " + str(throttle))
    t = max(-1.0, min(1.0, float(throttle)))
    if t > 0:
        set_fraction(PWM2_PATH, DRIVE_PERIOD_NS, 0.0)  # reverse off
        set_fraction(PWM3_PATH, DRIVE_PERIOD_NS, t)    # forward on
    elif t < 0:
        set_fraction(PWM3_PATH, DRIVE_PERIOD_NS, 0.0)  # forward off
        set_fraction(PWM2_PATH, DRIVE_PERIOD_NS, -t)   # reverse on
    else:
        set_fraction(PWM2_PATH, DRIVE_PERIOD_NS, 0.0)
        set_fraction(PWM3_PATH, DRIVE_PERIOD_NS, 0.0)

def brake(level):
    """
    Active braking: drive both legs with the same duty (0..1),
    which shorts the motor through the H-bridge (depending on wiring).
    """
    lvl = max(0.0, min(1.0, float(level)))
    set_fraction(PWM2_PATH, DRIVE_PERIOD_NS, lvl)
    set_fraction(PWM3_PATH, DRIVE_PERIOD_NS, lvl)

def coast():
    """High-impedance/coast: both legs off."""
    set_fraction(PWM2_PATH, DRIVE_PERIOD_NS, 0.0)
    set_fraction(PWM3_PATH, DRIVE_PERIOD_NS, 0.0)

# === Logging helper for tests ===
_t0 = time.monotonic()
def log(msg):
    """Timestamped print helper for the demo below."""
    dt = time.monotonic() - _t0
    print(f"[{dt:6.3f}s] {msg}")
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

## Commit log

2025-09-18 Adding current software state to the repo.
2025-09-18 Adding current use code versions
2025-11-12 Adding new CameraManager utility for manual fr.
2025-11-25 Added Teamphoto and updated power management section
2025-11-25 Adding power schematic
2025-11-25 Furthering Power management chapter
2025-11-25 Finalised Power chapter, Sensor chapter begun
2025-11-25 Camera chapter begun
2025-11-25 Sensor chapter andvances
2025-11-25 Finalising Power and Sense
2025-11-25 Adding Media, furthering mobility
    [All small Parts.3mf]
2025-11-25 Adding BOM
